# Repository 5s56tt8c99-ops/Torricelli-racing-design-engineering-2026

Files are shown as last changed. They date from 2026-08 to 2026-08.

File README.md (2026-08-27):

This project shows the creation and CFD analysis of a formula 1 in schools car that took part at the triveneto regional finals of 2026.
The files are aimed to show a visible comparison between the qualification car (preliminary phase) and the final car. The software used are Autodesk Fusion and Ansys discovery.

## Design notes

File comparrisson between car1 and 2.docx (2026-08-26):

CONFRONTO FRA VETTURA FASE 1 CON VETTURA FASE 2

DI PRIMO IMPATTO (piano parallelo al piano xy)

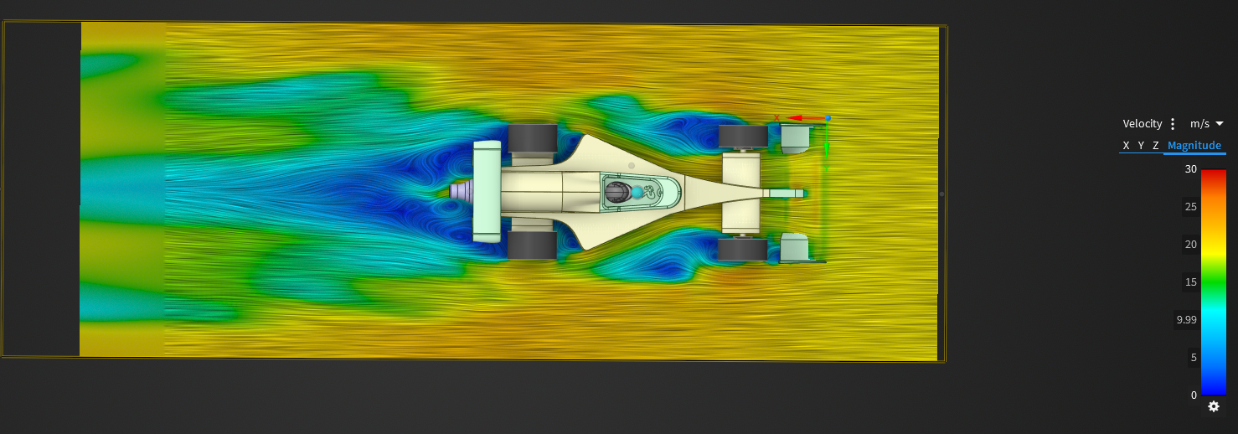
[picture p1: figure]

VS

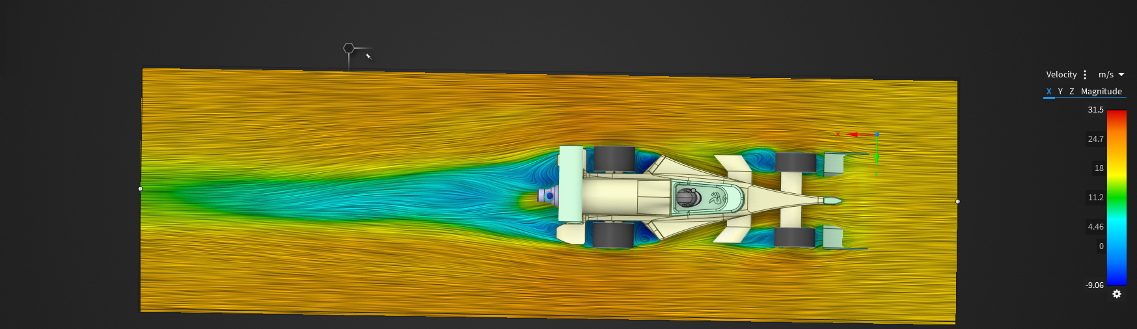
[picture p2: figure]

Già senza introdurre formule e dati è evidente analizzando solo la colorazione che corrisponde alla velocità dell’aria in m/s si possono notare grandi miglioramenti.

Innanzitutto il wake sia posteriore che anteriore si è ristretto notevolmente, oltre ad aver diminuito la sua intensità (colore più chiaro indica aria più veloce). Questo è sicuramente stato favorito dal restringimento dell’asse anteriore che lo ha avvicinato al main body permettendogli di essere “aspirato” dai flussi più veloci a centro vettura.

Il posteriore adesso è praticamente privo dei vortici che aveva prima, limitando l’effetto di “risucchio” della bassa pressione e riducendo cosi notevolmente il drag.

DI PRIMO IMPATTO (piano parallelo all’asse xz)

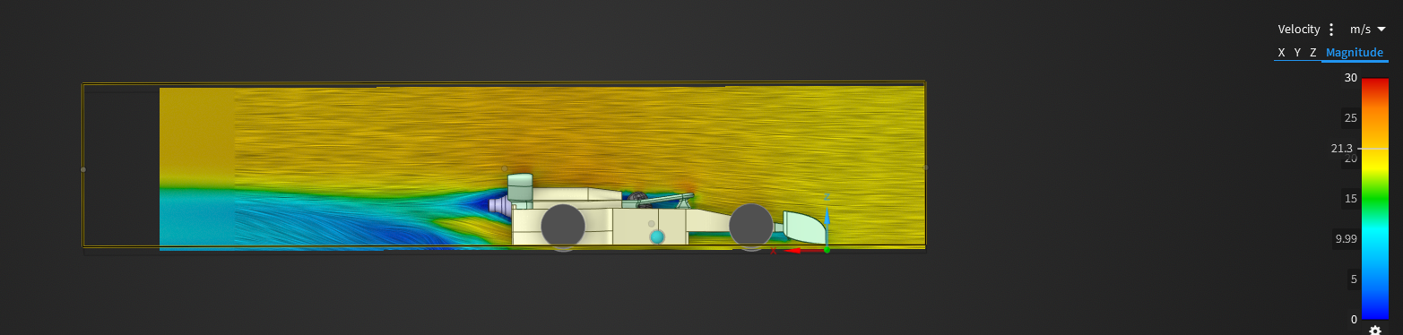
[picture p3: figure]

vs

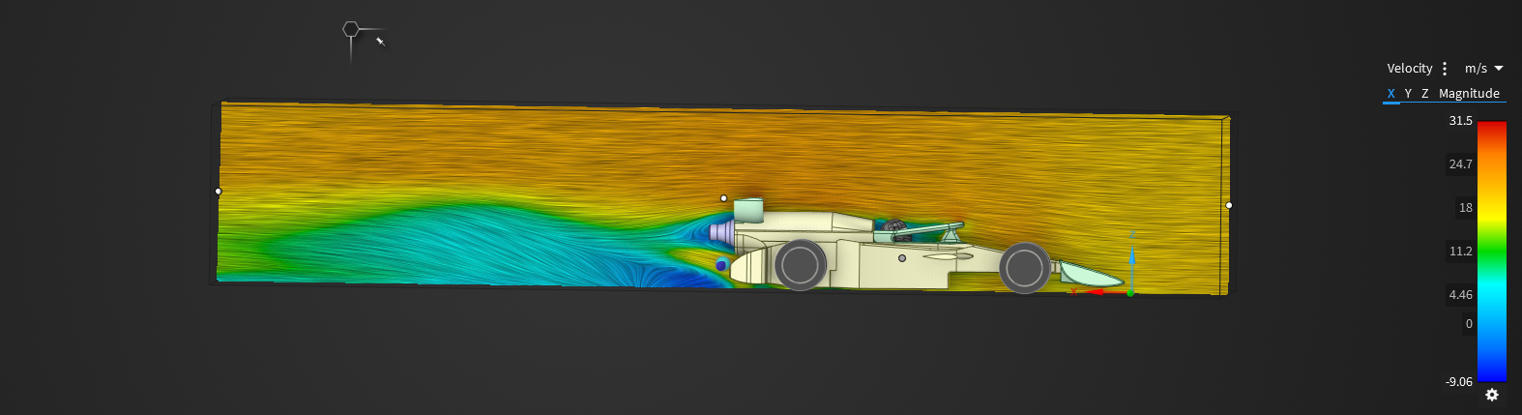
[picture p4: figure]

In questa sezione il guadagno della nuova vettura è un po’ meno evidente. Nonostante il wake posteriore sia più ampio è caratterizzato da aria più veloce e meno vorticosa, cosa che compensa il leggero aumento di dimensione.

NUMERI ALLA MANO

Vettura selezioni:

la prima vettura ha registrato ad una velocità di 70km/h (19.44m/s) una drag force totale di 0.523N con una superficie frontale di 26.32cm^2. Ciò le attribuisce un coefficiente di attrito dinamico di 0.85

C_d =(2∙0.523)/(1.225∙(19.44)^2 ∙0.002632)≈0.85

La nuova vettua ha registrato ad una velocità sempre di 70km/h (19.44m/s) una drag force totale di

C_d =(2∙0.459)/(1.225∙(19.44)^2 ∙0.002116)≈0.94

Nel confronto fra i due coefficienti aereodinamici ottenuti sembrerebbe che la vettura precedente abbia un netto vantaggio rispetto alla nuova. Ciò che fa storcere il naso è la discrepanza fra drag reale e coefficiente. Questa apparente contraddizione è dovuta al modo in cui il Cd è ottenuto. È infatti un parametro adimensionale normalizzato rispetto all’area frontale. La prima vettura pur avendo area frontale maggiore riesce a “dissolvere” il proprio drag all’interno della formula per il coefficiente, facendolo apparire minore. Ciò però non rispetta necessariamente la realtà perché va tenuto conto dei flussi attorno alla vettura e l’analisi prima dimostra come in realtà la prima vettura sia peggiore della seconda nonostante Cd inferiore.

ARIA ATTORNO AL MAIN BODY ALTEZZA HALO E GUIDATORE (piano parallelo all’asse xz)

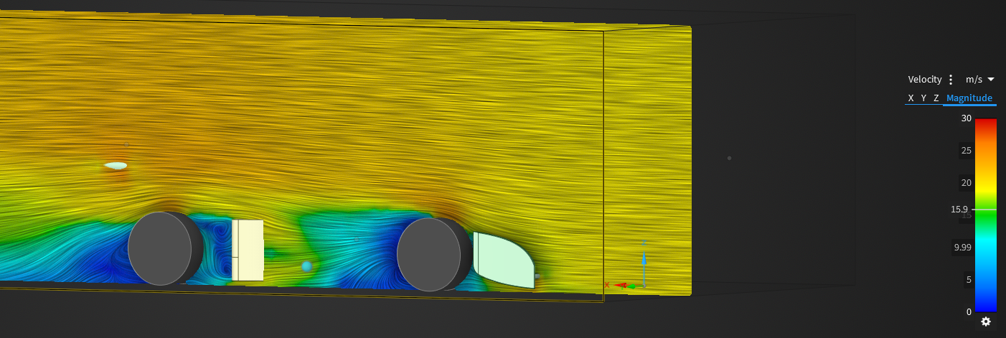
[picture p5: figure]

Vs

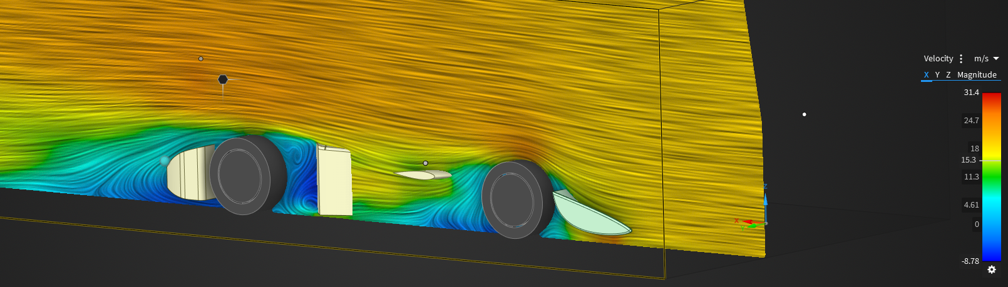
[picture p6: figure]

Ottima l’implementazione delle ali del main body che contribuiscono a velocizzare l’aria verso il posteriore. Approvato anche l’utilizzo di estrattori posteriori dietro le ruote che hanno la medesima funzione delle ali. Grazie a loro l’aria del wake è molto più veloce e meno vorticosa.

FONDO (piano parallelo al piano xy)

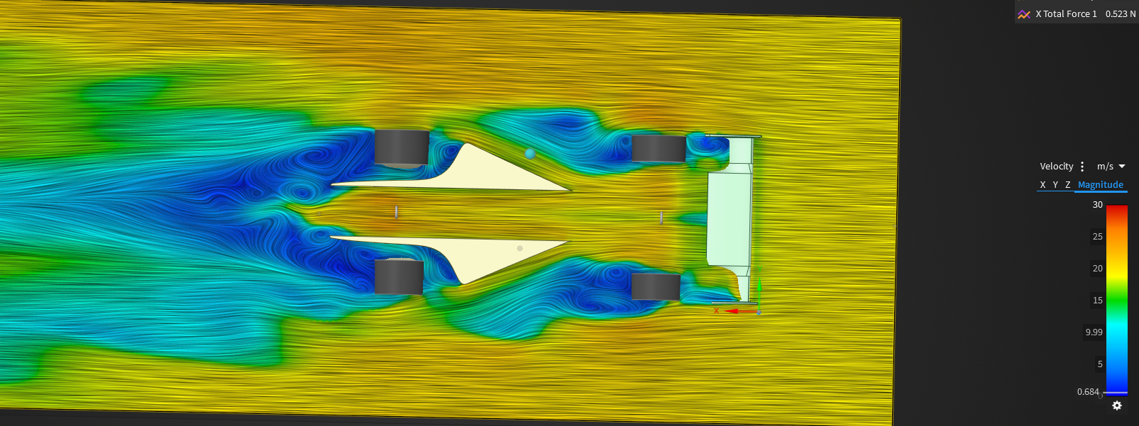
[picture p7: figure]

Vs

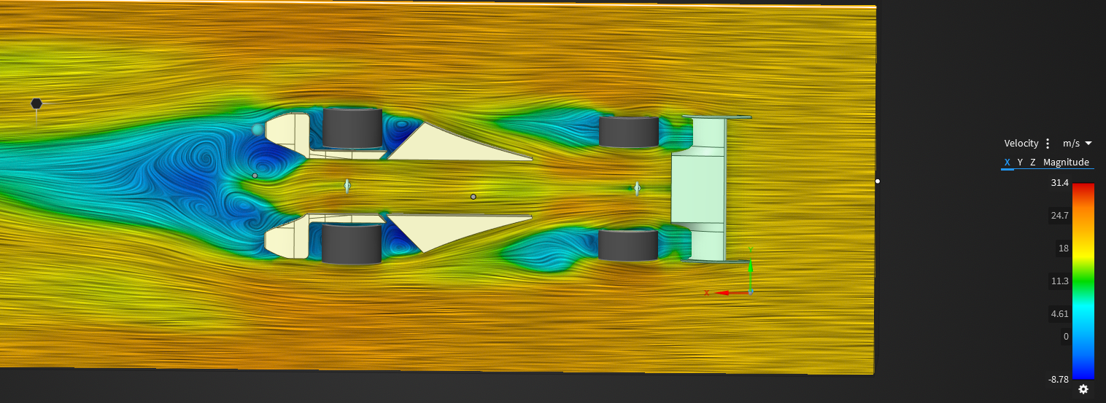
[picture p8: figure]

La vista sul fondo conferma ciò che era stato anticipato nella sezione “colpo d’occhio”. Wake anteriore notevolmente ridotto e ristretto e vorticosità posteriore migliorata. Non fanno molto secondo me i piccoli canali davanti alle ruote posteriore in quanto non ci sono miglioramenti tangibili

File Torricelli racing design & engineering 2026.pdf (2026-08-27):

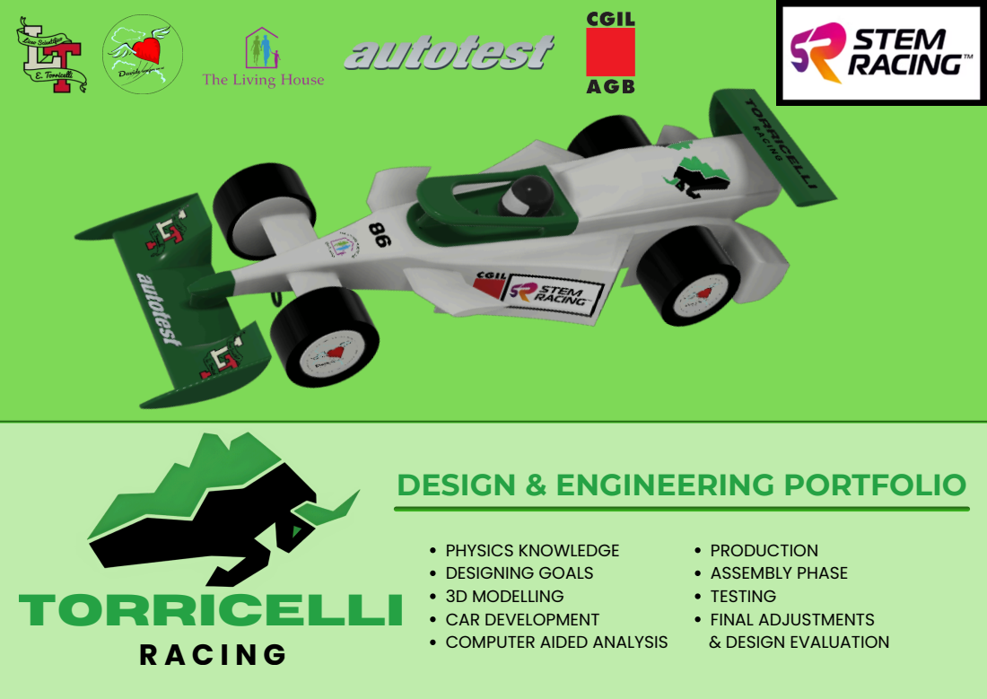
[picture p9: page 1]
TORRICELLI; PRODUCTION ASSEMBLY PHASE TESTING FINAL ADJUSTMENTS & DESIGN EVALUATION

DESIGN & ENGINEERING PORTFOLIO

PHYSICS KNOWLEDGE
DESIGNING GOALS
3D MODELLING
CAR DEVELOPMENT
COMPUTER AIDED ANALYSIS

Understanding airflow is essential to develop a high-performance F1 car. While fluid dynamics provides the theoretical framework for fluid motion, aerodynamics focuses specifically on the interaction between air and the vehicle’s surfaces. This interaction is critical since it severely affects the car’s stability, speed, and overall energy efficiency. We prioritized the optimization of four key aerodynamic forces: drag, downforce, lift, and thrust.

FLUID DYNAMICS & AERODYNAMICS

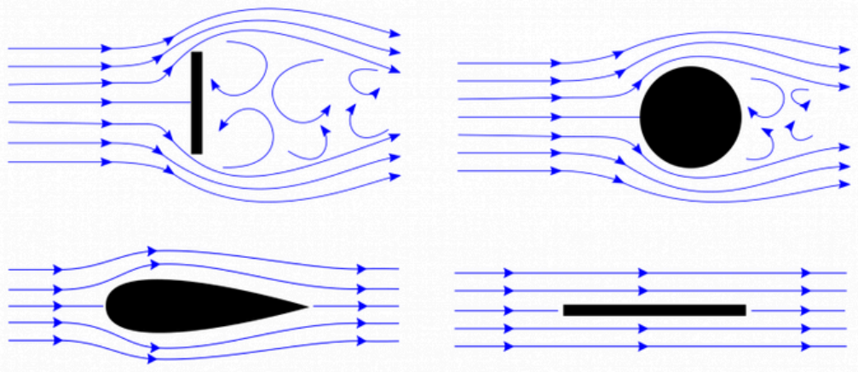
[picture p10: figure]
FOTO

Drag opposes forward motion and consists of form drag, which is dictated by the car’s geometry, and skin friction, caused by surface roughness. To minimize resistance, we implemented a streamlined frame and high-quality surface finishing to maintain laminar flow and reduce turbulence.

MINIMIZING DRAG

Vehicle acceleration is governed by Newton’s Second Law:

NEWTON’S LAWS & ACCELERATION

/ | /

Since the thrust from the CO₂ cartridge is constant, reducing mass is the most effective way to maximize acceleration. The key to peak performance relies on balancing this thrust against aerodynamic forces (drag, downforce, and lift) to ensure the car achieves maximum speed without compromising stability.

Taking this law into account, we have reduced the weight of the whole car from approx. 84g to approx. 47g.

ADVANCED AERODYNAMIC EFFECTS

The Coandă effect guides airflow along curved surfaces, boosting downforce and reducing turbulence, while the Magnus effect, caused by spinning bodies, alters trajectories. These two principles were taken into account during the CFD analysis, as they are fundamental concepts in fluid dynamics. Their effects are not directly imposed but naturally emerge from the simulation. By accurately defining the geometry, rotation, and boundary conditions, CFD can capture how airflow attaches to surfaces and how rotating bodies influence the flow.

Our main goal was to reduce the weight of the car to the bare minimum and minimize the area of impact while also trying to keep the slipstream as clean as possible. The total weight has been significantly reduced; in fact, we have gone from a total weight of around 84g to a total weight of around 47g.

THE MAIN GOAL | THE FRONT WING

For the front wing, our goal was to have cleaner airflow in the middle and direct the airflow over the front wheels. We also wanted to make the endplates longer to reach the endgate faster.

THE REAR WING

For the rear wing we aimed for a neutral airfoil and we decided on an asymmetrical design to
reduce the area of impact.

THE BODY

We wanted the body to move the air around and above the rear wheels and to clean that air after it passes those same wheels. It also had to keep the airflow under the car clean.

THE FRONT WHEEL SUPPORTS

For these supports, we wanted them to cover both the inside and outside of the wheel to reduce the rotating surface of the wheel. They should also have minimal impact on the airflow.

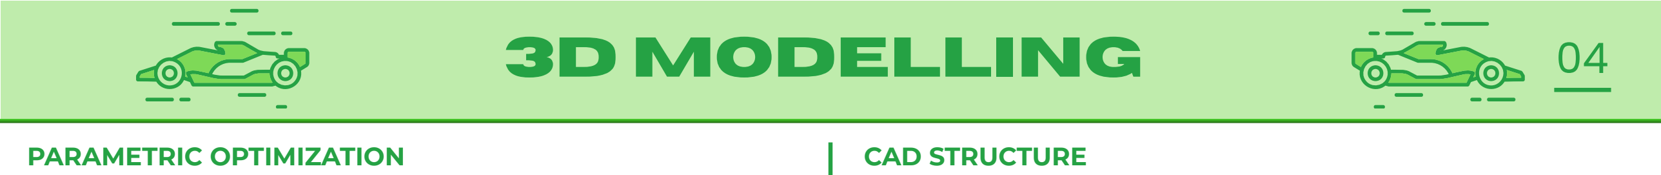
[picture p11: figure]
3D MODELLING; PARAMETRIC OPTIMIZATION; CAD STRUCTURE

We developed a flexible CAD structure to reconfigure the chassis and power unit axis. Reducing the wheel diameter from 30 mm to 28 mm .

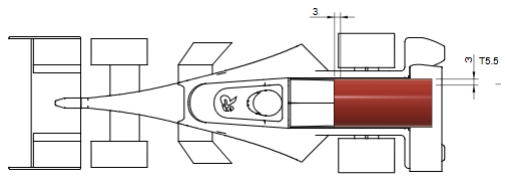
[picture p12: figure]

We adjusted the design to strictly respect the virtual cargo and free volume requirements. We collaborated with Ziptec to optimize CNC tool paths. Removed un-millable vertical geometries and applied 1 mm fillets .

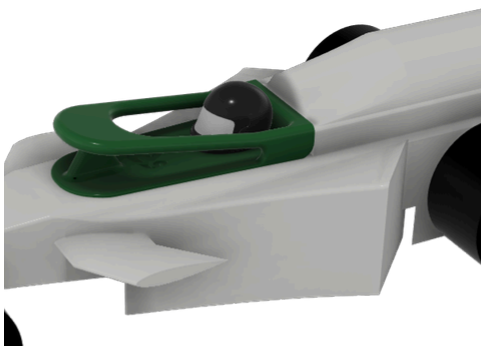
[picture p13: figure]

We refined the transitions between the winglets and the main body.

We utilized Autodesk Fusion for interference checks between components. Multiple 3D test prints were produced to identify
the optimal mechanical tolerance for the wheel bearings and
support systems.
OTHER OBJECTS | WINGLETS ADJUSTMENT

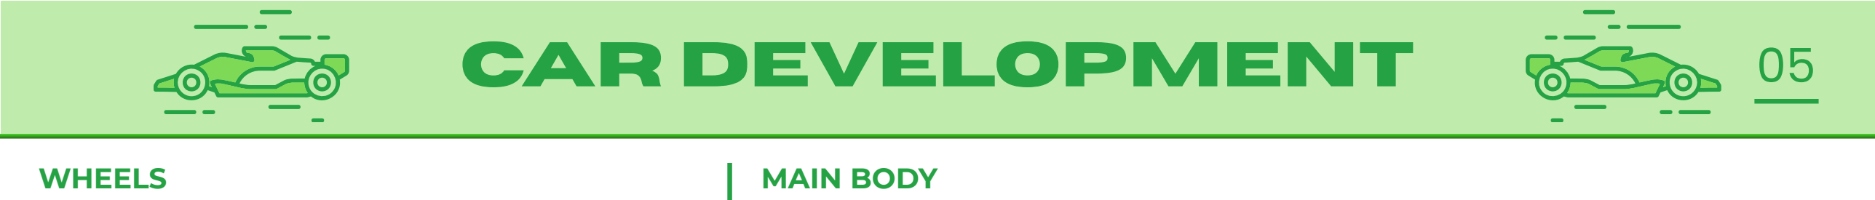
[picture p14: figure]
CAR DEVELOPMENT; WHEELS; MAIN BODY

For qualifying, the wheels were supplied by STEM Racing, but now we design and manufacture them ourselves. We reduced the wheel diameter (30mm to 28mm) to lower the Center of Gravity by 1mm. Recalibrated chassis height for high-speed balance.

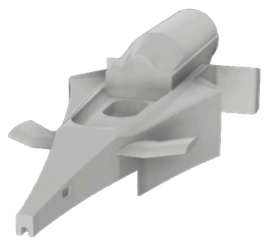
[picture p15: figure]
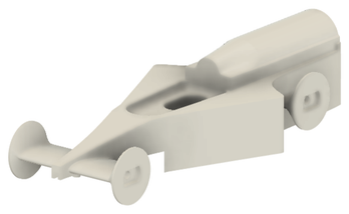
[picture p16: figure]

We resized the main body after the first prototype exceeded the STEM block width. Ensured 100% legal volume for the virtual cargo. We have also designed some ‘fins’ that allow air to flow smoothly from the front wheels to the rear wheels and on to the extruder.
We finally removed un-millable vertical parts following Ziptec’s feedback. Applied 1mm fillets to optimize CNC tool paths and structural strength.

The qualifying car did not have any air extractors, which meant that the airflow behind the wheels was very turbulent. We therefore designed some air extractors, taking inspiration from those on last year’s car.
We reinforced rear extractors to prevent deformation under air loads and improved management of wake turbulence behind the wheels.

The qualifying car didn

't have bearings, only bushings, whereas the current one has bearings. They minimize friction and mechanical play for maximum drivetrain rotation. We identified optimal bearing tolerances through iterative test prints.

EXTRACTORS

BEARINGS

FRONT WHEEL | REAR WHEEL

WINGS

For the front wing, it has been redesigned to be narrower, both to comply with the regulations and to suit the new bodywork dimensions, and also lower and sleeker to improve airflow both above and below it.

As for the rear wing, it has been designed with a single ring-shaped support, unlike the one used in qualifying, which greatly improves airflow. Furthermore, it has been designed asymmetrically to reduce the area of impact and improve airflow.

FRONT WING

REAR WING

For the CFD analysys we used ansys fluent. Although this software was new to us, it didn’t take us long to adapt to the changes. We compared our protoype from the previous competition with differerent possible changes and chose the ones that performed the best.

BODY TOP VIEW

Both the rear and front wake have significantly reduced in width and intensity. The rear is almost virtually free of the vortices it had before,
limiting the low-pressure
suction effect and thus
significantly reducing drag.

THE SOFTWARE

BODY PROFILE

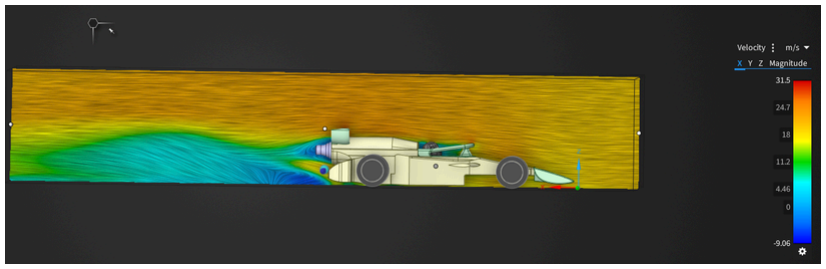
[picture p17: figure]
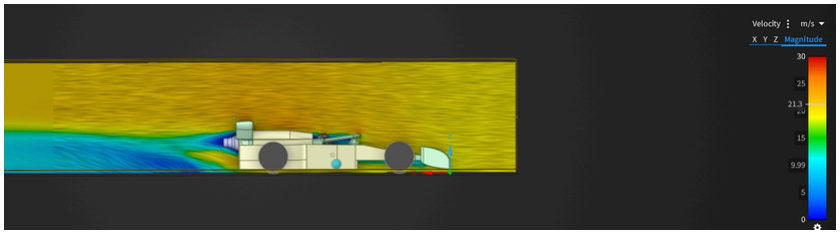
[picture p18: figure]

Although the rear wake is wider, it features faster, less turbulent air, which compensates for the slight increase in size.

BODY BOTTOM VIEW

WHEELS PROFILE | TOTAL DRAG AND AIR RESISTANCE

The wings on the main
body, help to channel air
more quickly toward the
rear. The use of rear
diffusers behind the
wheels, which serve the
same purpose as the
wings, is also effective.
Thanks to tese changes,
the wake is much faster
and less turbulent.

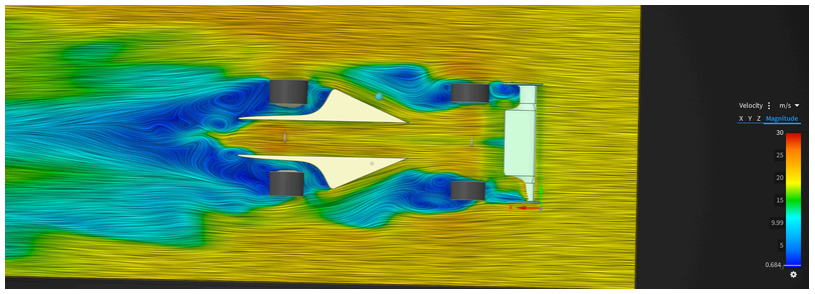
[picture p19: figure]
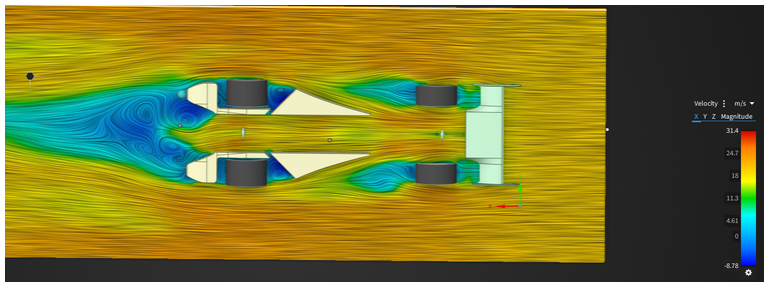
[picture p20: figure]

The front wake and the rear turbulence have been significantly reduced.

There was a significant improvement in total drag force, which decreased from approximately 0.6N to 0.459N. This improvement is undoubtedly due to the rear diffusers and the central wings, which, through the Coandă effect, facilitate airflow and help channel the air toward the diffusers. The frontal area of the car has decreased compared to the previous version, dropping to 21.16 cm²

This results in an overall reduction of the drag coefficient, which has fallen to 0.94.

INFILL | WEIGHT
5% | 4.55g
10% | 4.76g
15% | 4.9g

CAR WEIGHT PREDICTION

We had estimated a total weight of around 46g, but in the end, after adding the decals, we ended up with a weight of around 46.87g. The weight of the body cannot be altered, as it is not 3D-printed but milled from a block of polyurethane foam. Therefore, the weight of the car depends largely on the infill of certain components, such as the halo:

MANUFACTURING AND PRODUCTION

The milling machine was used to shape the block of polyurethane foam to make the body. The machine used for the process is a Mazak CV5-500.
To manufacture this part, five different milling tools were required: a Ø6 carbide end mill with 4 flutes, a Ø3 carbide ball end mill with 2 flutes, a Ø4 carbide end mill with 4 flutes, a Ø2 carbide end mill with 4 flutes, and a Ø6 carbide ball end mill with 2 flutes. The machining time for a single part is 58 minutes, while the programming time required is 8 hours. The machine setup time is 1 hour. The average power consumption of the machine, including the energy required for air production, is approximately 9 kW.
MILLING MACHINE | 3D PRINTER

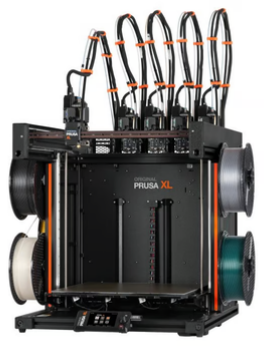
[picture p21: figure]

All the other parts of the car were 3D-printed. We used a Prusa printer because it has space for several spools, which allowed us to print more quickly. We used PLA for the components and PETG for the supports.

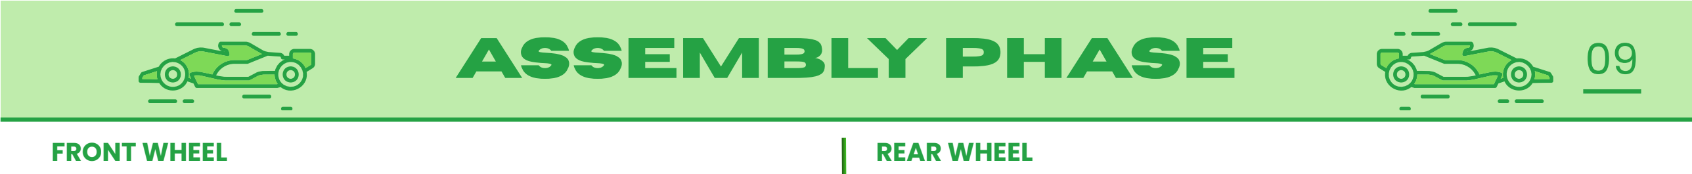
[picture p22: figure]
ASSEMBLY PHASE; FRONT WHEEL; REAR WHEEL

When assembling the front wheel, we first secured the wheel cap, then the bearing, and finally the bracket that will be attached to the car body.

When assembling the rear wheel, we first secured the wheel cap, then the bearing, and finally the bracket that will be attached to the car’s body.

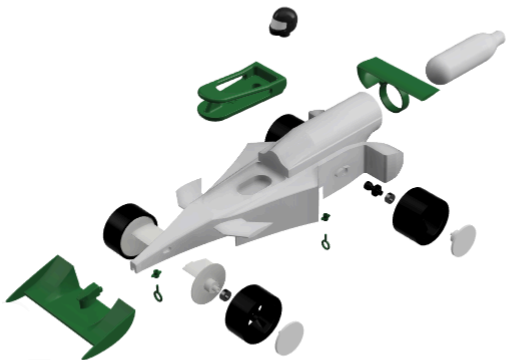
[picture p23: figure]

After assembling the wheel structure, we attached the front and rear wheels to the car using superglue.

We then attached the helmet to the halo and glued both to the body.

We made some PLA spacers for the hooks underneath, which were then glued to the body to allow the hooks to be screwed in.

Finally, we glued the front wing and rear wing to the body.

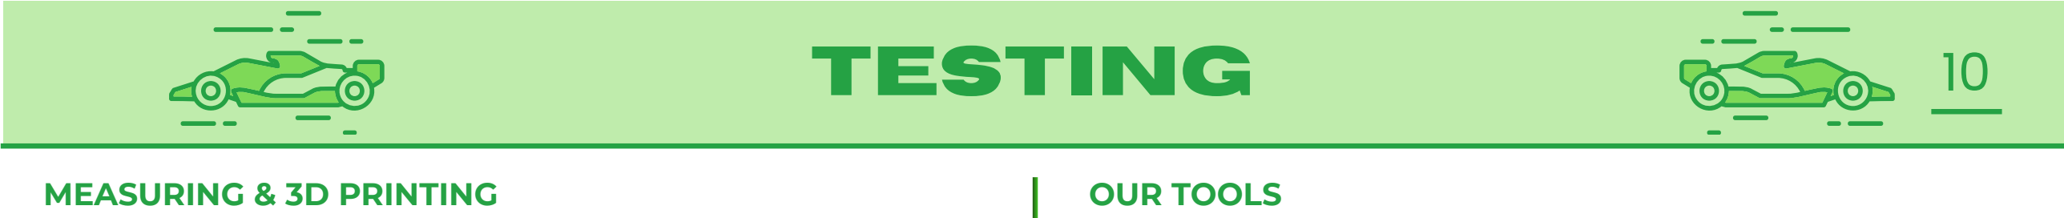
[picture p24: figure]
TESTING; MEASURING & 3D PRINTING; OUR TOOLS

We measured each component several times to ensure that everything complied with the regulations. Even during the modelling stage, we checked the dimensions and weight several times so as not to have to make too many prints. We carried out test prints to make sure we didn’t make any mistakes.


We had a range of saws at our disposal, both manual and electric, as well as calipers and scales of varying sensitivity. We also had several 3D printers available at the Fablab BZ, as well as a milling machine (which, however, was not used by us but by professionals)


We tested the various components by subjecting them to the same tests used in races. We tested the halo by applying a 2kg weight to it and the clips using 200g weights.

COMPETITION TESTS

FINAL ADJUSTMENTS & DESIGN EVALUATION; FINAL ADJUSTMENTS

In the end, we corrected a few minor printing errors and produced the stickers. We had a few issues with the sticker dimensions because the measurements provided in Fusion weren’t the same as those required for the machine settings; this was because, on the machine used for the stickers, the measurements could only be set from an additional border rather than from the edge of the sticker itself. Finally, we stuck on the halo, which we’d hoped would stay in place simply by fitting into the slot.

THE END


We have now reached the final stage of this project and are excited to compete on April 18th–19th. Over the past months, we have dedicated a great deal of time, effort, and commitment to developing our car, working step by step from the initial idea to the final product.
Throughout this journey, teamwork has been essential. By collaborating, solving problems, and continuously improving our design, we were able to achieve a result we are truly proud of. This project has not only strengthened our technical skills but also our ability to work efficiently as a team.
We are now looking forward to the competition, where we will have the opportunity to challenge ourselves against many strong teams and put all our work into practice.
We would like to sincerely thank BITZ FabLab in Bolzano for their support and for helping us turn our ideas into reality. A special thanks also goes to Ziptec for providing the milling machine, which played a key role in the manufacturing of our car.

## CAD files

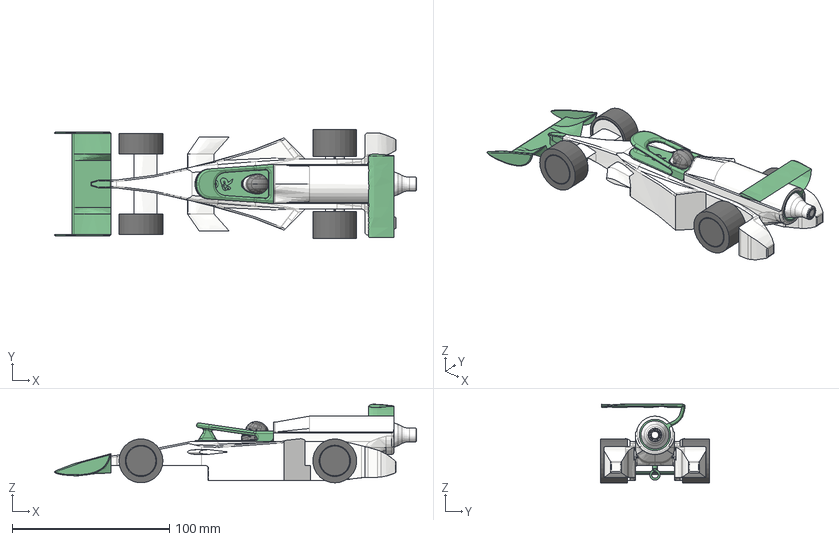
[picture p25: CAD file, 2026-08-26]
FINALCARV2.step
230.5 x 69.2 x 50.1 mm
rear left wheel
rear right wheel (1)
